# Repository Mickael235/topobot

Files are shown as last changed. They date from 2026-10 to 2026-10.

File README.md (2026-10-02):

# TopoBot

<p align="center">
  <strong>Autonomous holonomic robot for automated topographic surface-flatness inspection</strong><br>
  ENSIM × ESGT · 4th-year Engineering Project · 2025–2026
</p>

<p align="center">
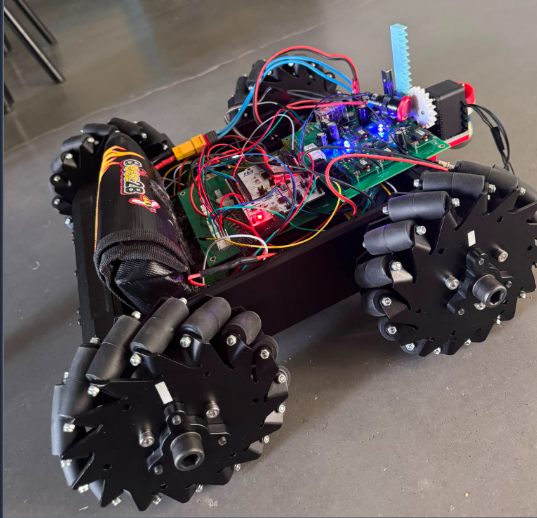
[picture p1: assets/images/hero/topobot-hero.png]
TopoBot holonomic mobile robot
  
</p>

<p align="center">
  <strong>STM32 F446RE · Raspberry Pi · Mecanum · Encoders · AX-12 · XBee · KiCad · Python · C</strong>
</p>

---

## Project overview

**TopoBot** is a holonomic mobile robot developed to automate the repetitive part of a topographic surface-flatness survey.

In a conventional workflow, an operator manually moves a reflector from point to point while another operator operates the total station. TopoBot was designed to replace this manual point-by-point displacement with a configurable robotic mission:

1. define the measurement grid;
2. navigate to each waypoint;
3. deploy the topographic prism;
4. trigger / acquire the measurement;
5. recover the coordinates;
6. store and export the results.

The project combines **robotics, embedded control, electronics, radio communication, software supervision and topographic instrumentation** in one integrated prototype.

> **Project status:** the main hardware/software building blocks were integrated and validated on the prototype. Final industrial-grade accuracy, complete odometry/total-station fusion and a full production flatness campaign remain future work.

---

## Project at a glance

| Item | Implementation |
|---|---|
| Mobile base | Lynxmotion A4WD3 with 4 Mecanum wheels |
| Real-time controller | STM32 Nucleo F446RE |
| High-level computer | Raspberry Pi 4 |
| Motor power stage | 2 × Sabertooth motor drivers |
| Motion feedback | 4 incremental wheel encoders |
| Prism mechanism | AX-12 servomotor + rack-and-pinion mechanism |
| Station communication | XBee S2C radio link + serial / RS232 interface |
| Supervision | TopoBot Manager on tablet / browser |
| Data storage | SQLite on Raspberry Pi |
| Export | CSV |
| Real-time control loop | 100 Hz |
| Project budget | €500 |
| Actual project cost | €318.26 |
| Team | 4 engineering students |

### Design target

The functional specification targeted a configurable survey grid up to **50 m × 50 m**, with a nominal **0.5 m grid spacing** and a **40 mm spherical reflector**.

This is a **design requirement**, not a claim that the complete 50 × 50 m campaign was validated during the project.

---

# 1. Problem and mission

Manual surface inspection with a total station is repetitive: the reflector must be moved and positioned at many points, while measurements are triggered and recorded.

TopoBot aims to transform this workflow into a supervised autonomous sequence.

<p align="center">
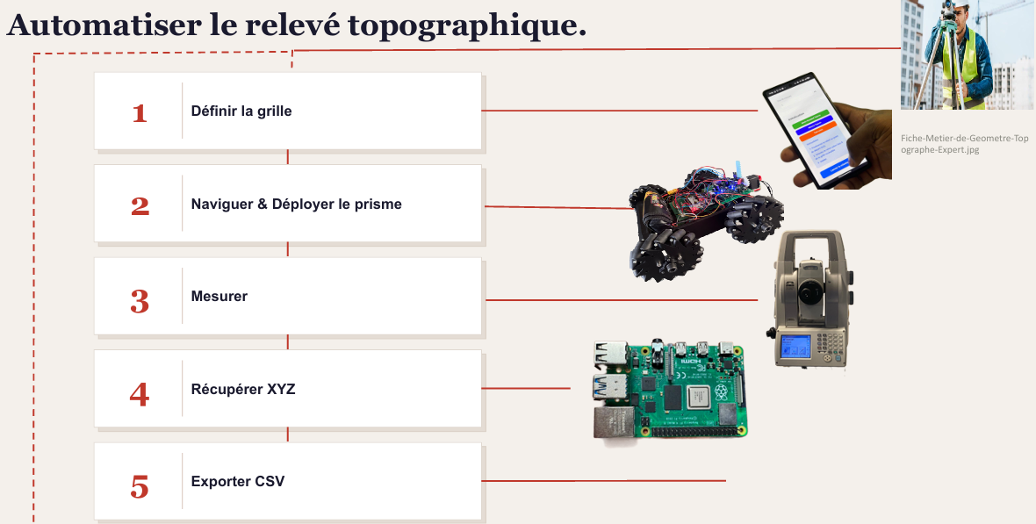
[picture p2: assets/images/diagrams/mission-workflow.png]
TopoBot automated topographic survey workflow
  
</p>

## Nominal survey cycle

```text
Define grid
    ?
Generate waypoints
    ?
Navigate to waypoint
    ?
Stabilize robot
    ?
Deploy prism
    ?
Trigger total-station measurement
    ?
Recover XYZ / angles / distance
    ?
Retract prism
    ?
Store point in SQLite
    ?
Send progress to TopoBot Manager
    ?
Next waypoint
    ?
Export mission data to CSV
```

The trajectory is generated as a **boustrophedon path**: the direction alternates from one grid row to the next to reduce unnecessary travel.

---

# 2. Functional architecture

The robot must interact with the surveyor, the surface, the total station, the energy source and the safety environment.

<p align="center">
  TopoBot functional architecture and main requirements
</p>

The main service functions are:

| Ref. | Function | Main requirement |
|---|---|---|
| FP1 | Move and orient the reflector | Configurable grid, 40 mm reflector |
| FC1 | Communicate with the total station | XBee S2C radio link, commands + coordinates |
| FC2 | Provide configuration and monitoring | Tablet / smartphone interface |
| FC3 | Provide energy autonomy | Rechargeable battery |
| FC4 | Operate in an indoor environment | Flat surface, future obstacle/drop detection |
| FC5 | Respect safety/environment constraints | Emergency stop and safe integration |

---

# 3. Robot structure

TopoBot is not a single-controller robot. It uses a **distributed architecture** in which the computational responsibilities are separated.

## Three control levels

```mermaid
flowchart LR
    UI["Tablet / Browser<br><b>TopoBot Manager</b>"]
    PI["Raspberry Pi 4<br><b>Mission supervisor / middleware</b>"]
    MCU["STM32 F446RE<br><b>Real-time motion controller</b>"]

    UI <-->|Network / Web interface| PI
    PI <-->|Binary serial protocol| MCU
```

### Level 1 — Tablet / front-end

The operator uses TopoBot Manager to:

- connect to the robot;
- configure the survey area;
- choose the grid spacing;
- initialize the measurement mode;
- launch the mission;
- monitor progress;
- read logs and telemetry;
- stop the robot;
- export results.

### Level 2 — Raspberry Pi / middleware

The Raspberry Pi acts as the high-level computer. It is responsible for:

- mission generation;
- waypoint sequencing;
- communication with the STM32;
- communication with the total station;
- measurement orchestration;
- SQLite data storage;
- WebSocket progress updates;
- CSV export;
- serving the supervision application.

### Level 3 — STM32 / real-time control

The STM32 F446RE performs the time-critical functions:

- encoder acquisition;
- odometry;
- motion state machine;
- closed-loop motor control;
- Sabertooth command generation;
- emergency-stop handling;
- AX-12 prism control;
- execution of high-level motion orders.

This separation keeps real-time control local to the microcontroller while the Raspberry Pi focuses on supervision and mission logic.

---

# 4. Complete hardware architecture

```mermaid
flowchart TD
    APP["TopoBot Manager<br>Tablet / PC"]
    RPI["Raspberry Pi 4<br>Mission supervisor"]
    STM["STM32 F446RE<br>100 Hz real-time control"]
    PCB["Custom control board<br>KiCad / JLCPCB"]

    ENC["4 wheel encoders"]
    SAB["2 × Sabertooth<br>motor drivers"]
    MOT["4 DC motors<br>4 Mecanum wheels"]
    AX["AX-12 servo<br>Prism deployment"]
    ESTOP["Emergency stop"]
    BATT["Battery monitoring"]

    XB1["XBee S2C #1"]
    XB2["XBee S2C #2"]
    RS232["MAX3232 / RS232"]
    TOPCON["Robotic total station"]

    APP <-->|Supervision| RPI
    RPI <-->|Binary serial protocol| STM

    ENC --> STM
    STM --> PCB
    PCB --> SAB
    SAB --> MOT
    STM --> AX
    ESTOP --> PCB
    BATT --> PCB

    RPI <-->|USB / UART serial| XB1
    XB1 <-. "Radio" .-> XB2
    XB2 <-->|Serial| RS232
    RS232 <-->|RS232| TOPCON
```

<p align="center">
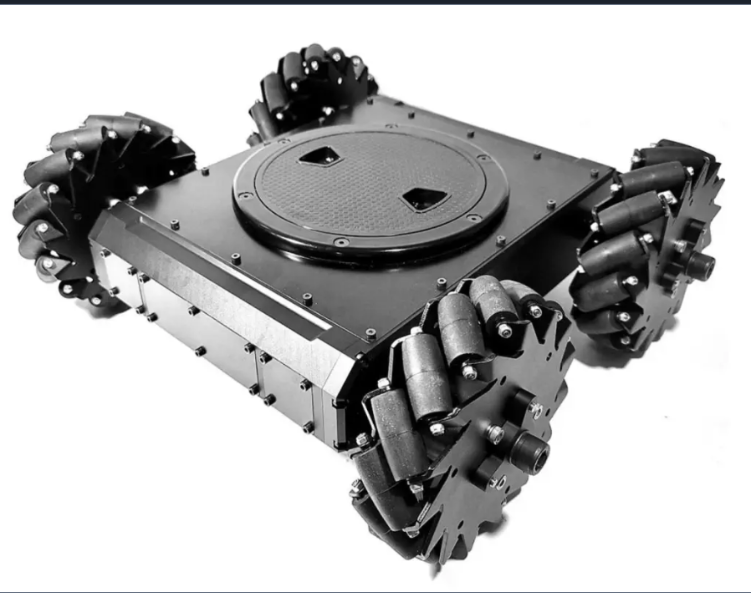
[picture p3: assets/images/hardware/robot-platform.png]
TopoBot physical robot
  
</p>

---

# 5. Holonomic Mecanum platform

The Lynxmotion A4WD3 base uses four Mecanum wheels, allowing longitudinal, lateral and rotational motion.

## Wheel-direction combinations

| Motion | Front Left | Front Right | Rear Left | Rear Right |
|---|---:|---:|---:|---:|
| Forward | + | + | + | + |
| Backward | - | - | - | - |
| Left translation | - | + | + | - |
| Right translation | + | - | - | + |
| Left rotation | - | + | - | + |
| Right rotation | + | - | + | - |

The current survey mission mainly uses **translations with a constant orientation**. Nevertheless, the command interface preserves the full pose parameter:

```text
MOVE_TO(x, y, theta)
```

This keeps the architecture extensible toward complete pose control.

## Physical testing

Early tests demonstrated the expected Mecanum motion but also revealed parasitic rotation during straight translations due to wheel/motor asymmetry.

This led to:

- individual wheel testing;
- lower-speed validation;
- exploitation of encoder feedback;
- progressive closed-loop tuning.

---

# 6. STM32 real-time control

The embedded firmware is organised around several modules:

```text
STM32 firmware
+-- Mecanum kinematics
+-- Encoder acquisition
+-- Odometry
+-- PID / motion control
+-- Robot state machine
+-- Raspberry Pi protocol
+-- AX-12 prism control
+-- Safety / robot configuration
```

The repository contains the STM32 project in:

```text
firmware/stm32/
```

## Robot state machine

The controller uses the following main states:

```mermaid
stateDiagram-v2
    [*] --> IDLE
    IDLE --> MOVING: MOVE_TO
    MOVING --> SETTLING: target reached
    SETTLING --> DONE: position confirmed
    DONE --> IDLE
    MOVING --> ERROR: fault
    SETTLING --> ERROR: fault
    IDLE --> ESTOP: emergency stop
    MOVING --> ESTOP: emergency stop
    SETTLING --> ESTOP: emergency stop
```

Main states:

- `IDLE` — waiting for a command;
- `MOVING` — moving toward the target;
- `SETTLING` — stabilizing around the waypoint;
- `DONE` — waypoint reached and confirmed;
- `ERROR` / `ESTOP` — error or emergency stop.

The Raspberry Pi only sends the next waypoint after receiving a `DONE` status.

---

# 7. Raspberry Pi ? STM32 protocol

The Raspberry Pi does not directly control the motors.

It sends high-level commands to the STM32 using a lightweight binary protocol:

```text
[ START | CMD | LEN | PAYLOAD | CRC ]
```

The project uses a simple XOR-based CRC over the command, payload length and payload.

## Main commands

| Command | Role |
|---|---|
| `MOVE_TO` | Reach target pose `(x, y, ?)` |
| `STOP` | Immediate robot stop |
| `RESET_ODOM` | Reset odometry before a mission |
| `GET_STATUS` | Read position, speed and current state |
| `DEPLOY_PRISM` | Deploy the topographic prism |
| `RETRACT_PRISM` | Retract the prism |

The STM32 returns status frames such as:

```text
STATUS
DONE
ERROR
```

These messages allow the Raspberry Pi backend to orchestrate the mission without interfering with the real-time control loop.

---

# 8. Automatic mission logic

The mission is generated from:

```text
Zone width  = X
Zone length = Y
Grid step   = p
```

The backend generates the waypoint set:

```text
(xi, yj)
xi = i × p
yj = j × p
```

and orders them in a boustrophedon trajectory.

## Exact mission order

```text
1. RESET_ODOM
   +- Reset the robot local reference before starting.

2. Generate waypoints
   +- Build the complete boustrophedon measurement grid.

3. For each waypoint:
   +- Send MOVE_TO(x, y, ?)
   +- Wait for STM32 STATUS updates
   +- Continue only after DONE

4. If measurement mode is enabled:
   +- DEPLOY_PRISM
   +- Trigger / request Topcon measurement
   +- Recover measurement values
   +- RETRACT_PRISM

5. Save measurement
   +- Timestamp + local coordinates + station data ? SQLite

6. Notify front-end
   +- Mission progress and current data ? WebSocket

7. Continue with next waypoint

8. End mission
   +- Export the recorded dataset to CSV
```

<p align="center">
  TopoBot mission order
</p>

A **station-independent test mode** was also kept. In this mode the robot can execute the grid with simulated measurement values, making it possible to debug navigation without depending on the topographic instrument.

---

# 9. Prism deployment mechanism

The topographic reflector is mounted on a rack-and-pinion mechanism actuated by an **AX-12 servomotor**.

The mechanism is responsible for:

```text
RETRACTED
    ?
DEPLOY_PRISM
    ?
Prism positioned for measurement
    ?
Total-station acquisition
    ?
RETRACT_PRISM
    ?
Robot resumes navigation
```

This sequence is synchronized with waypoint validation so that measurements are not requested while the robot is still moving.

---

# 10. Custom electronics

A custom control board was designed in **KiCad**, manufactured by **JLCPCB**, assembled and integrated into the robot.

<p align="center">
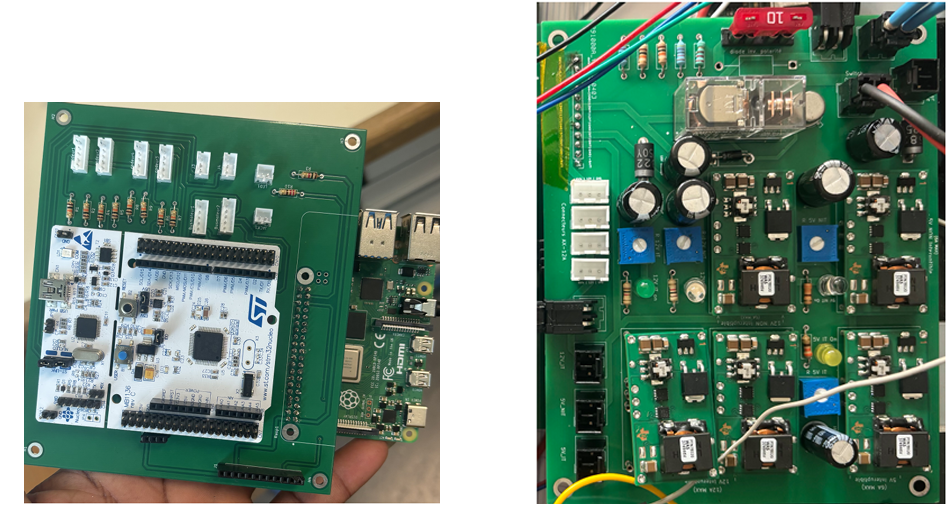
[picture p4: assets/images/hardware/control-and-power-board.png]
TopoBot custom control and power electronics
  
</p>

The control electronics centralize:

- four encoder interfaces;
- STM32 connectivity;
- Sabertooth motor-control connections;
- AX-12 interface;
- emergency-stop circuitry;
- centralized power management;
- analog battery monitoring;
- expansion ports for future ultrasonic sensors.

The pre-existing power board was reused, while the **control board was redesigned specifically for this project**.

The KiCad project and Gerber manufacturing files are available under:

```text
hardware/control-board/
+-- kicad/
+-- manufacturing/
    +-- gerbers/
```

---

# 11. XBee radio link and total-station interface

TopoBot communicates with the robotic total station through a dedicated radio/serial chain.

<p align="center">
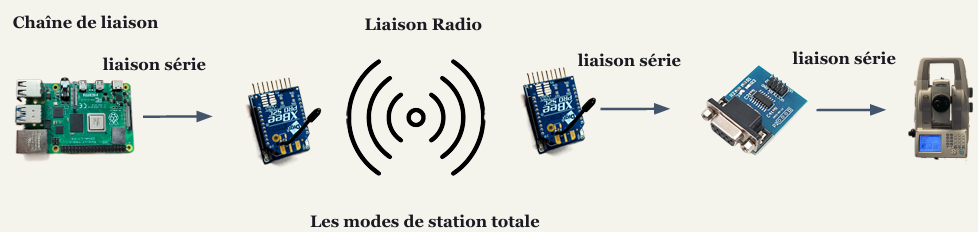
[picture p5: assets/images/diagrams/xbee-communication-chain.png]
XBee communication chain between Raspberry Pi and total station
  
</p>

## Communication chain

```text
Raspberry Pi
    ¦
    ¦ USB / UART serial
    ?
XBee S2C #1
    ))) RADIO (((
XBee S2C #2
    ¦
    ¦ Serial
    ?
MAX3232 / RS232 converter
    ¦
    ¦ RS232
    ?
Robotic total station
```

## XBee configuration used during the project

| Parameter | Configuration |
|---|---|
| Baud rate | 9600 |
| Data bits | 8 |
| Parity | None |
| Stop bits | 1 |
| Flow control | None |
| Channel | `C` / `0x0C` |
| PAN ID | `B332` |

The modules were configured using **Digi XCTU**.

## Total-station operating modes

The project explored three main station modes:

### Standard (`std`)
High-precision fixed measurement using fine targeting.

### Tracking (`trk`)
Fast tracking / targeting of a moving reflector.

### Continuous tracking
Continuous acquisition of distances and horizontal/vertical angles.

The automated acquisition sequence uses the station together with the robot prism workflow to recover the current measured point and feed it back into the mission data.

> **Known limitation:** the XBee radio link showed intermittent reliability problems during field testing. Improving the radio layer is one of the main future-work items.

---

# 12. TopoBot Manager

**TopoBot Manager** is the supervision interface designed for tablet use.

Its purpose is to hide the complexity of the robot, STM32, Raspberry Pi and total station behind a guided workflow.

<p align="center">
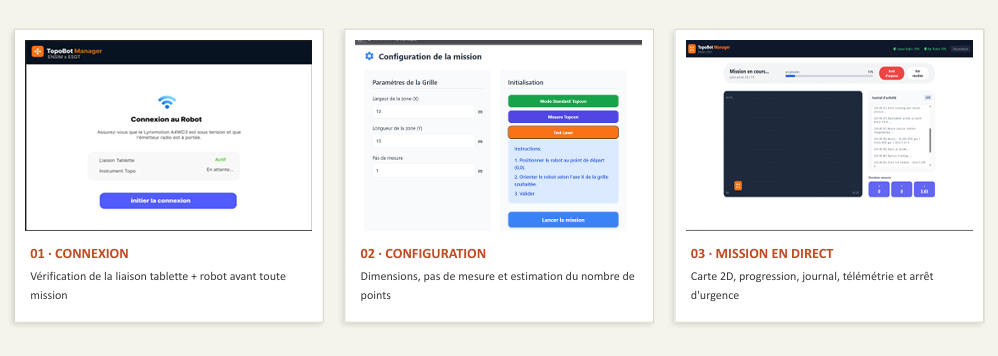
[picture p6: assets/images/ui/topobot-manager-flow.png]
TopoBot Manager connection, configuration and live mission screens
  
</p>

The application follows three main user stages.

## 01 — Connection

Before a mission starts, the interface verifies that the robot and measurement system are reachable.

Typical checks include:

- robot / Raspberry Pi connectivity;
- total-station link state;
- initialization readiness.

The operator cannot proceed until the system is ready.

## 02 — Mission configuration

The operator defines:

- survey width `X`;
- survey length `Y`;
- measurement step `p`;
- measurement mode.

The backend uses these values to determine the grid and generate the mission waypoints.

<p align="center">
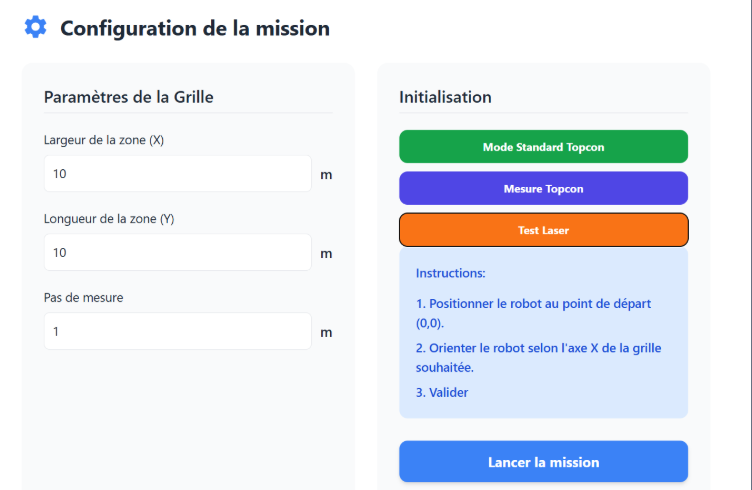
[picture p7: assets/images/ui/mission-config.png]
TopoBot Manager mission configuration
  
</p>

## 03 — Live mission supervision

During execution, the interface displays:

- mission progress;
- current point;
- 2D map of the grid;
- robot position;
- completed measurement points;
- activity/event log;
- latest measurement values;
- radio / system information;
- emergency-stop action.

<p align="center">
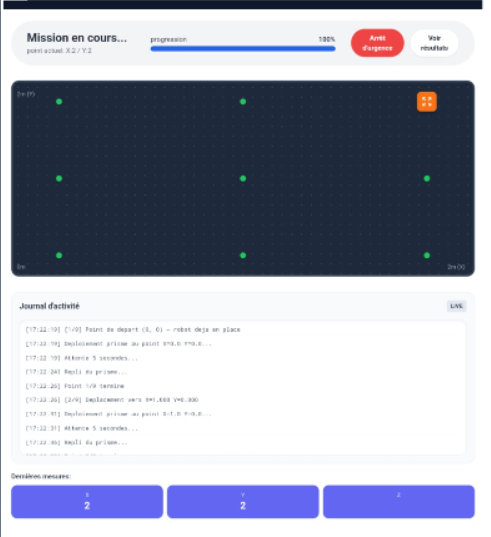
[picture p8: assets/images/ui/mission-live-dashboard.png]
TopoBot Manager live mission dashboard
  
</p>

---

# 13. Software communication layers

The complete information flow can be summarized as:

```text
+--------------------------------------+
¦ Tablet / Browser                    ¦
¦ TopoBot Manager                     ¦
¦ - configuration                     ¦
¦ - live map                          ¦
¦ - progress                          ¦
¦ - logs                              ¦
¦ - emergency stop                    ¦
+--------------------------------------+
                    ¦ HTTP / WebSocket
                    ?
+--------------------------------------+
¦ Raspberry Pi                        ¦
¦ Middleware / Mission Supervisor     ¦
¦ - route generation                  ¦
¦ - waypoint orchestration            ¦
¦ - SQLite                            ¦
¦ - CSV export                        ¦
¦ - total-station communication       ¦
+--------------------------------------+
                ¦               ¦
        Binary serial           ¦ XBee / serial
                ¦               ¦
                ?               ?
+----------------------+   +---------------------+
¦ STM32 F446RE         ¦   ¦ Robotic total      ¦
¦ - odometry           ¦   ¦ station            ¦
¦ - encoders           ¦   ¦ - measurement      ¦
¦ - PID                ¦   ¦ - tracking         ¦
¦ - motors             ¦   ¦ - XYZ / angles     ¦
¦ - AX-12              ¦   +---------------------+
+----------------------+
```

---

# 14. Data acquisition and export

Each measurement point is stored locally on the Raspberry Pi.

The project uses **SQLite** for mission data and exposes the final dataset through **CSV export**.

## Recorded fields

| Field | Meaning |
|---|---|
| `ID` | Unique measurement-point identifier |
| `HEURE` | Acquisition timestamp |
| `X`, `Y` | Local planar coordinates |
| `HZ` | Horizontal station angle |
| `V` | Vertical station angle |
| `DIST` | Radial distance measured by the station |

The mission data lifecycle is:

```text
Connection
    ?
Geometry configuration
    ?
Survey supervision
    ?
SQLite storage
    ?
CSV export
```

The CSV format was chosen to keep the results directly usable in spreadsheets and topographic post-processing tools.

---

# 15. Validation

The project was developed using progressive integration and physical tests.

## Tests performed

- individual motor-direction tests;
- Mecanum wheel-combination tests;
- forward/backward translation;
- lateral translation;
- encoder acquisition;
- odometry;
- Raspberry Pi ? STM32 communication;
- high-level `MOVE_TO` commands;
- robot state-machine behavior;
- AX-12 prism deployment/retraction;
- XBee radio communication;
- total-station operating modes;
- TopoBot Manager connection/configuration/live monitoring;
- mission generation and waypoint sequencing;
- station-independent simulated-measurement mode.

## Current validation status

| Subsystem | Status |
|---|---|
| Mecanum basic motion | ? Validated |
| STM32 real-time architecture | ? Implemented |
| Encoder feedback / odometry | ? Integrated |
| Raspberry Pi ? STM32 protocol | ? Implemented |
| High-level waypoint mission logic | ? Implemented |
| AX-12 prism deployment | ? Integrated and validated |
| Custom control PCB | ? Designed, manufactured and assembled |
| TopoBot Manager | ? Functional |
| Total-station communication modes | ? Exercised |
| XBee field robustness | ?? Functional but unreliable in some tests |
| Closed-loop tuning | ?? Requires finer adjustment |
| Odometry + total-station fusion | ?? Future work |
| Complete production flatness campaign | ?? Still to be finalized |

The goal of this repository is to present the **real engineering state of the prototype**, including both validated subsystems and remaining technical limitations.

---

# 16. Engineering challenges encountered

## Wheel synchronization

The first physical tests revealed unwanted rotation during straight movement.

Probable causes included:

- different mechanical behavior between motors;
- left/right timing asymmetry;
- open-loop control limitations.

Encoder feedback and closed-loop control were introduced to improve trajectory stability.

## Odometry drift

Wheel odometry accumulates errors when the wheels slip or the ground is irregular.

A future version should fuse:

```text
Wheel odometry
      +
High-precision total-station coordinates
      ?
Corrected robot localization
```

## Radio robustness

The XBee solution proved useful for prototyping but showed intermittent signal losses.

A more robust professional radio solution would be preferable for field deployment.

## Wiring reliability

The prototype contains a significant amount of point-to-point wiring. A future revision should use:

- locking connectors;
- improved cable routing;
- additional functions integrated directly onto the PCB.

## Active safety

Obstacle/drop sensors were planned in the architecture but were not fully operational in the final prototype.

---

# 17. My contribution

This was a **four-person team project** with distinct technical work packages.

My contribution focused primarily on **control, kinematics and motion validation**, including:

- development and validation of robot movement behavior;
- Mecanum motion testing;
- trajectory-execution testing;
- analysis of encoder feedback and positioning errors;
- participation in odometry / motion-control integration;
- contribution to waypoint and mission-motion logic;
- integration and testing of the AX-12 prism mechanism;
- physical prototype testing and debugging.

The complete project also includes major contributions from the other team members in supervision/UI, XBee communication and electronics/PCB integration.

---

# 18. Team organization

| Team member | Main work package |
|---|---|
| Bénéwindé Kontiebo | Project management · Supervision · HMI |
| Aymane Fariss | Communication · XBee / total-station link |
| Arsène Nguenang Youkap | Electronics · PCB · hardware integration |
| **Michael Essomba** | **Control · kinematics · AX-12 prism mechanism** |

The project was managed using an agile-inspired workflow with regular synchronization and milestone reviews.

---

# 19. Budget and reuse strategy

The project operated under a **€500 budget**.

| Metric | Value |
|---|---:|
| Available budget | €500 |
| Actual project cost | **€318.26** |
| Remaining budget | €181.74 |
| Budget utilization | ~64% |

A significant part of the platform was reused from previous cohorts:

- Lynxmotion chassis;
- DC motors;
- Mecanum wheels;
- Sabertooth drivers;
- XBee modules;
- AX-12 servo;
- prism mechanism;
- existing power board.

New spending focused mainly on the Raspberry Pi, STM32 boards, control electronics, passive components and PCB manufacturing.

---

# 20. Repository structure

```text
topobot/
+-- README.md
+-- .gitignore
¦
+-- assets/
¦   +-- images/
¦   ¦   +-- hero/
¦   ¦   ¦   +-- topobot-hero.png
¦   ¦   ¦
¦   ¦   +-- diagrams/
¦   ¦   ¦   +-- functional-architecture.png
¦   ¦   ¦   +-- mission-workflow.png
¦   ¦   ¦   +-- xbee-communication-chain.png
¦   ¦   ¦
¦   ¦   +-- hardware/
¦   ¦   ¦   +-- robot-platform.png
¦   ¦   ¦   +-- control-and-power-board.png
¦   ¦   ¦   +-- total-station.png
¦   ¦   ¦   +-- robot-cad-render.png
¦   ¦   ¦
¦   ¦   +-- ui/
¦   ¦       +-- topobot-manager-flow.png
¦   ¦       +-- mission-config.png
¦   ¦       +-- mission-live-dashboard.png
¦   ¦
¦   +-- video/
¦       +-- topobot-demo.mp4
¦
+-- docs/
¦   +-- presentation/
¦   +-- report/
¦   +-- technical/
¦
+-- firmware/
¦   +-- stm32/
¦
+-- hardware/
¦   +-- control-board/
¦       +-- kicad/
¦       +-- manufacturing/
¦           +-- gerbers/
¦
+-- software/
    +-- raspberry-pi/
    ¦   +-- tests/
    ¦
    +-- topobot-manager/
        +-- backend/
        +-- frontend/
```

Generated build files, local databases, virtual environments, IDE temporary files and dependency directories are intentionally excluded from version control.

---

# 21. Technologies

### Embedded systems

`C` · `STM32 F446RE` · `STM32CubeIDE` · `HAL`

### Robotics and control

`Mecanum kinematics` · `Encoders` · `Odometry` · `PID` · `State machine` · `AX-12`

### High-level software

`Python` · `Raspberry Pi` · `SQLite` · `WebSocket`

### Communication

`UART` · `Serial` · `XBee S2C` · `RS232`

### Electronics

`KiCad` · `PCB design` · `Gerber` · `JLCPCB`

### Instrumentation

`Robotic total station` · `Topographic prism` · `Tracking`

### Development

`Git` · `GitHub` · `Hardware testing` · `Technical documentation`

---

# 22. Demo

A short demonstration of the physical prototype is available here:

### [? Watch the TopoBot demo](assets/video/topobot-demo.mp4)

---

# 23. Documentation

Detailed engineering documentation is available in [`docs/`](docs/).

Main documents:

- [Final project report](docs/report/Rapport_final.pdf)
- [Project presentation](docs/presentation/TopoBot_Presentation.pdf)
- [STM32 firmware documentation](docs/technical/firmware/)
- [Hardware and wiring documentation](docs/technical/hardware/)
- [Raspberry Pi documentation](docs/technical/raspberry-pi/)
- [Testing documentation](docs/technical/tests/)
- [Odometry, PID and validation documentation](docs/technical/advanced/)

---

# 24. Future work

The next engineering priorities are:

1. **PID tuning**  
   Reduce oscillations and trajectory error.

2. **Odometry calibration**  
   Improve the estimation of `x`, `y` and `?`.

3. **Odometry / total-station sensor fusion**  
   Correct wheel-slip drift using high-precision station feedback.

4. **Radio reliability**  
   Replace or harden the XBee communication chain for field use.

5. **Active navigation safety**  
   Integrate obstacle, drop and stair detection.

6. **Wiring redesign**  
   Reduce point-to-point wiring and use locking connectors.

7. **Large-grid validation**  
   Validate longer missions and repeated surveys under realistic conditions.

8. **Full flatness campaign**  
   Complete the end-to-end autonomous survey and compare results against a reference workflow.

---

# 25. Project outcome

TopoBot evolved from an inherited mechanical platform into an integrated robotic prototype combining:

- a redesigned embedded architecture;
- STM32 real-time motion control;
- Raspberry Pi mission supervision;
- custom control electronics;
- Mecanum mobility;
- encoder odometry;
- AX-12 prism deployment;
- XBee / total-station communication;
- tablet-based mission supervision;
- local measurement storage and CSV export.

The project demonstrates the feasibility of automating a topographic surface-inspection workflow while also identifying the engineering work still required to reach robust field deployment.

---

# Project team

**ENSIM × ESGT — Le Mans University**  
Academic year: **2025–2026**

- Bénéwindé Kontiebo
- **Michael Essomba**
- Arsène Nguenang Youkap
- Aymane Fariss

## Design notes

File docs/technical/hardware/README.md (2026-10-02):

# 2 — Matériel

Ce chapitre décrit les composants du robot et comment ils sont reliés.
Voir aussi :
- [Brochage STM32](Brochage_STM32.md) — tableau complet des broches
- [Câblage](Cablage.md) — détail des bus et des liaisons

## 2.1 Liste des composants principaux

| Composant | Rôle | Interface vers le STM32 |
|---|---|---|
| **Carte STM32 Nucleo F446RE** | Calculateur temps réel | — |
| **Raspberry Pi** | Superviseur (serveur, station, web) | USB → USART2 (via ST‑Link) |
| **2× contrôleurs Sabertooth** | Pilotage des 4 moteurs DC | UART4 (PC10), bus partagé |
| **4× moteurs DC + réducteur** | Entraînement des roues mecanum | via Sabertooth |
| **4× encodeurs en quadrature** | Odométrie | TIM2, TIM3, TIM4, TIM8 |
| **Servo AX12 Dynamixel** | Déploiement du prisme | UART5 (PC12) |
| **Bouton d'arrêt d'urgence (ARU)** | Sécurité | GPIO PB14 |
| **Relais d'alimentation puissance** | Coupe l'alim moteurs | GPIO PA5 (Power_enable) |
| **Module XBee** | Liaison vers la station Topcon | USB sur la Raspberry Pi (FTDI) |
| **Station Topcon MS1AX** | Mesures topographiques | via XBee |
| **Prisme topographique** | Réflecteur visé par la station | monté sur le servo AX12 |
| **Capteur niveau batterie** | Mesure tension (ADC) | PA4 (ADC1_IN4) |

## 2.2 Schéma des liaisons

```
                         ┌───────────────────────────┐
                         │      STM32 F446RE          │
                         │                            │
  Raspberry Pi ──USB────►│ USART2 (PA2/PA3) 115200    │
  (ST-Link série)        │                            │
                         │ UART4  (PC10)  ────────────┼──► Sabertooth #1 (addr 128) ─► moteurs FL, RL
                         │   bus série partagé 9600   ┼──► Sabertooth #2 (addr 129) ─► moteurs FR, RR
                         │                            │
                         │ UART5  (PC12)  1 Mbps ─────┼──► Servo AX12 (prisme)
                         │                            │
                         │ TIM2 (PA0/PA1) ◄───────────┼─── Encodeur FR  🔴 hors service
                         │ TIM3 (PA6/PA7) ◄───────────┼─── Encodeur RR  🟢
                         │ TIM4 (PB6/PB7) ◄───────────┼─── Encodeur FL  🔴 hors service
                         │ TIM8 (PC6/PC7) ◄───────────┼─── Encodeur RL  🟢
                         │                            │
                         │ PB14 ◄─────────────────────┼─── Bouton ARU
                         │ PA5  ────────────────────► relais alim puissance
                         │ PA4  ◄── tension batterie  │
                         └────────────────────────────┘

  Raspberry Pi ──USB(FTDI)──► XBee ))) ((( XBee ──► Station Topcon MS1AX
```

## 2.3 Alimentation

- Une **batterie** alimente la partie puissance (moteurs via Sabertooth).
- Le STM32 active la puissance via le **relais sur PA5** (`Power_enable_stm`).
  Au démarrage le firmware met PA5 à l'état haut (cf. `main.c`, juste après
  l'init) pour autoriser le courant vers les Sabertooth.
- La **tension batterie** est lisible sur l'ADC (PA4 / `Battery_level`). Cette
  mesure n'est pas encore exploitée dans le logiciel — piste d'amélioration
  (cf. [passation](../08_Passation/README.md)).

> ⚠️ Couper la puissance (relais / batterie) avant toute intervention sur le
> câblage. Le bouton ARU coupe la **commande** mais vérifiez toujours
> physiquement.

## 2.4 État du matériel (fin d'année)

| Élément | État | Remarque |
|---|---|---|
| Moteurs + Sabertooth | 🟢 | Les 4 roues répondent (voir polarités dans `mecanum.c`) |
| **Les 4 encodeurs** (TIM2/3/4/8) | 🟡 | **Fonctionnent**, mais comptage intermittent à cause de la carte de commande (voir ci‑dessous) |
| Carte de commande (interface encodeurs) | 🟡 | **Problèmes intermittents** : certains tics ne remontent pas tant que la carte/les connecteurs ne sont pas bien en place |
| Servo AX12 | 🟢 | Déploie / replie le prisme |
| Bouton ARU | 🟢 | Avec filtrage anti‑parasites moteurs (debounce) |
| Station Topcon + XBee | 🟡 | Fonctionne mais sensible à la config série / au timing |
| Mesure batterie | 🔴 | Câblée mais non exploitée par le logiciel |

> ⚠️ **Les 4 encodeurs sont fonctionnels.** Le problème vient de la **carte de
> commande** : selon son état (connecteurs, contacts), certains encodeurs
> peuvent **ne pas compter** ponctuellement, ce qui **fausse l'odométrie**.
>
> **PROCÉDURE OBLIGATOIRE avant chaque test** : lancer `test_encoders.py`,
> **tourner chaque roue à la main** une par une, et vérifier que les tics de
> chacune des 4 roues augmentent bien. Si une roue ne compte pas → vérifier /
> repositionner la carte de commande **avant** de continuer, sinon tous les
> déplacements asservis seront faux.
>
> Note : le code firmware actuel (`robot_config.h`, mode `ODOM_REAR_ONLY=1` et
> commentaires « HORS SERVICE ») reflète un **ancien diagnostic** où seuls les
> encodeurs arrière étaient lus. Comme les 4 fonctionnent, ce mode peut être
> repassé à `0` **une fois le comptage des 4 roues confirmé** (voir
> [firmware](../03_Firmware_STM32/Modules.md) et
> [passation](../08_Passation/README.md)).

## 2.5 Cartes électroniques (KiCad)

Les cartes d'interface/alimentation conçues cette année seront documentées dans
le dossier [`07_KiCad/`](../07_KiCad/README.md) : déposez‑y les fichiers
sources KiCad (schémas, routage, BOM, gerbers).

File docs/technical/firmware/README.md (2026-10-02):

# 3 — Firmware STM32

Le firmware est le programme temps réel embarqué dans le STM32 F446RE. Il vit
dans le dossier `Core/` (le dossier `Drivers/` est la bibliothèque HAL générée,
à ne pas modifier).

Voir aussi :
- [Protocole de communication](Protocole_Communication.md) — trames Pi ↔ STM32
- [Modules firmware](Modules.md) — description fichier par fichier

## 3.1 Environnement et compilation

- **IDE** : STM32CubeIDE (basé sur Eclipse + GCC ARM).
- **Ouvrir le projet** : *File ▸ Open Projects from File System…* → dossier
  `ProjetRobot`. Le `.cproject` / `.project` sont déjà présents.
- **Configuration matérielle** : `ProjetRobot.ioc` (CubeMX). Double‑cliquez
  pour modifier le brochage / les périphériques ; CubeMX régénère ensuite les
  fonctions `MX_*_Init` dans `main.c`.
- **Compiler** : marteau 🔨 (*Build*). Le binaire `.elf` est produit dans
  `Debug/`.
- **Flasher / déboguer** : insecte vert 🐞 (*Debug*) ou *Run*. La carte Nucleo
  embarque un ST‑Link, le flash se fait par USB sans matériel supplémentaire.

> **Règle d'or CubeMX** : tout code que vous écrivez doit rester entre les
> balises `/* USER CODE BEGIN ... */` et `/* USER CODE END ... */`. Tout ce qui
> est en dehors est **écrasé** à chaque régénération depuis le `.ioc`.

## 3.2 Architecture logicielle

Le firmware est organisé en couches, du bas niveau au haut niveau :

```
        ┌─────────────────────────────────────────────┐
        │              main.c (boucle while)           │
        │  - init des périphériques                    │
        │  - TIM6 100 Hz → flag velocity_tick          │
        │  - appelle Protocol_Process + RobotControl   │
        └───────────────┬───────────────┬──────────────┘
                        │               │
        ┌───────────────▼──┐   ┌────────▼───────────────┐
        │  protocol.c       │   │  robot_control.c       │
        │  (dialogue Pi)    │   │  (machine d'états +    │
        │                   │   │   asservissement x,y)  │
        └───────────────────┘   └──┬─────────┬───────┬───┘
                                   │         │       │
                       ┌───────────▼─┐ ┌─────▼────┐ ┌▼────────┐
                       │ odometry.c   │ │ pid.c    │ │ mecanum.c│
                       │ (pose x,y,θ) │ │ (régul.) │ │ (roues + │
                       │              │ │          │ │ Sabertooth)│
                       └──────────────┘ └──────────┘ └──────────┘

                       ax12.c  ←  pilotage servo prisme (appelé par protocol.c)
```

## 3.3 La boucle de contrôle 100 Hz

C'est le cœur temps réel. Mécanisme :

1. **TIM6** est configuré à **100 Hz** (`main.c`, `MX_TIM6_Init`). À chaque
   débordement, son interruption met le flag `velocity_tick = 1` (et **rien
   d'autre** : aucun travail bloquant en interruption).
2. La boucle `while(1)` de `main.c` :
   - traite les trames reçues de la Pi (`Protocol_Process()`),
   - et quand `velocity_tick` est levé, appelle `RobotControl_Update()`.
3. `RobotControl_Update()` (à 100 Hz) :
   - met à jour l'**odométrie** (lecture des encodeurs),
   - filtre l'**ARU**,
   - selon l'état, calcule les vitesses (asservissement) et les envoie aux
     **Sabertooth** via `Mecanum_SetVelocity()`.

> **Pourquoi l'envoi Sabertooth se fait en boucle principale et pas en
> interruption ?** L'envoi de 4 paquets à 9600 bauds prend ≈ 17 ms. Si on le
> faisait dans l'interruption TIM6 (priorité haute), il masquerait la réception
> USART2 pendant 17 ms → risque d'**overrun** (octets perdus, réception bloquée).
> En le faisant dans la boucle principale, la réception peut préempter
> normalement. **Ce point reste fragile** — voir
> [passation](../08_Passation/README.md).

## 3.4 La machine d'états du robot

Définie dans `robot_control.h` (`RobotState_t`) :

| État | Signification |
|---|---|
| `ROBOT_IDLE` | En attente. Peut recevoir des vitesses manuelles (`CMD_SET_VELOCITY`). |
| `ROBOT_MOVING` | Déplacement asservi en cours vers une cible (x, y). |
| `ROBOT_SETTLING` | (réservé) stabilisation sur la cible. |
| `ROBOT_DONE` | Cible atteinte et stabilisée. |
| `ROBOT_ESTOP` | Arrêt d'urgence (bouton ARU). |
| `ROBOT_ERROR` | Erreur (hors limites de grille, etc.). |

Transitions principales :
- `CMD_MOVE_TO` → `MOVING` ; convergence (pose stable `SETTLE_CYCLES` cycles) → `DONE`.
- ARU appuyé → `ESTOP` (depuis n'importe quel état).
- `CMD_STOP` / `CMD_RESET_ODOM` → retour à `IDLE`.

## 3.5 Stratégie d'asservissement (important)

L'asservissement de position est un **proportionnel pur saturé avec zone
morte**, pas un vrai PID. Choix volontaire, documenté dans `robot_control.c` :

```
vx = saturation(KP · erreur_x , ±VELOCITY_CAP) ; si |vx| < zone_morte → 0
vy = saturation(KP · erreur_y , ±VELOCITY_CAP) ; si |vy| < zone_morte → 0
```

Raisons :
1. **Pas d'intégrale (I)** → pas de windup, pas de dérive à l'arrêt.
2. **Pas de dérivée (D)** → pas de pic au démarrage qui saturait la commande.
3. Garder la sortie dans la plage `[zone_morte, VELOCITY_CAP]` où **toutes les
   roues répondent uniformément** (régime validé empiriquement vers 0,10 m/s).

S'y ajoutent :
- une **rampe d'accélération** (slew rate) pour démarrer en douceur,
- une **correction séquentielle des axes** : quand vx et vy sont proches en
  magnitude, on ne garde que l'axe dominant (sinon la cinématique mecanum met
  une paire de roues à ≈0 → déséquilibre).

Tous les paramètres (gains, plafonds, seuils, tolérances) sont centralisés dans
**`robot_config.h`** — c'est le fichier à éditer pour régler le comportement.

## 3.6 Fichier de configuration : `robot_config.h`

**À lire en entier.** Il regroupe :
- mapping et polarités des encodeurs,
- handles UART et adresses Sabertooth,
- paramètres AX12 (ID, positions, débit),
- dimensions du robot (rayon de roue, empattements),
- calibration de l'odométrie (`TICKS_PER_METER`),
- gains et limites de l'asservissement,
- fréquence de la boucle de contrôle.

> ⚠️ Plusieurs constantes portent la mention « à recalibrer » ou « à mesurer ».
> Voir [Calibration](../06_Calibration_Depannage.md).

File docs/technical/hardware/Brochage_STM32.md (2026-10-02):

# Brochage STM32 F446RE

Tableau complet des broches utilisées, extrait de la configuration CubeMX
(`ProjetRobot.ioc`). Les **étiquettes** (« Label ») sont celles définies dans
le `.ioc` et reprises dans le code.

> Pour modifier le brochage, ouvrez `ProjetRobot.ioc` dans STM32CubeIDE
> (double‑clic) plutôt que d'éditer le code à la main : CubeMX régénère
> ensuite les fonctions d'init dans `main.c`.

## Moteurs (signaux PWM + direction)

> Note : les moteurs sont en réalité pilotés par les **Sabertooth via UART4**
> (protocole série), pas directement par ces PWM. Ces broches PWM/DIR
> proviennent d'une première approche « pont en H direct » et restent câblées
> dans le `.ioc`. Le firmware actuel n'utilise PAS ces PWM pour la marche
> (voir `mecanum.c`).

| Broche | Label | Fonction | Périphérique |
|---|---|---|---|
| PA8  | Moteur_1_PWM | PWM moteur 1 | TIM1_CH1 |
| PA9  | Moteur_2_PWM | PWM moteur 2 | TIM1_CH2 |
| PA10 | Moteur_3_PWM | PWM moteur 3 | TIM1_CH3 |
| PA11 | Moteur_4_PWM | PWM moteur 4 | TIM1_CH4 |
| PB1  | Moteur_1_DIR | Direction moteur 1 | GPIO sortie |
| PB2  | Moteur_2_DIR | Direction moteur 2 | GPIO sortie |
| PB3  | Moteur_3_DIR | Direction moteur 3 | GPIO sortie |
| PB4  | Moteur_4_DIR | Direction moteur 4 | GPIO sortie |

## Encodeurs (mode quadrature)

| Broches | Labels | Roue | Timer | État |
|---|---|---|---|---|
| PA0 / PA1 | CodDA / CodDB | FR (avant droite) | TIM2 (CH1/CH2) | 🟡 OK, dépend de la carte de commande |
| PA6 / PA7 | CodDA2 / CodDB2 | RR (arrière droite) | TIM3 (CH1/CH2) | 🟡 OK, dépend de la carte de commande |
| PB6 / PB7 | CodGB / CodGA | FL (avant gauche) | TIM4 (CH1/CH2) | 🟡 OK, dépend de la carte de commande |
| PC6 / PC7 | CodG2B / CodGA2 | RL (arrière gauche) | TIM8 (CH1/CH2) | 🟡 OK, dépend de la carte de commande |

> **Les 4 encodeurs fonctionnent.** Mais selon l'état de la **carte de
> commande**, le comptage peut être intermittent → **vérifier les 4 roues avec
> `test_encoders.py` avant chaque test** (voir
> [Matériel §2.4](README.md#24-état-du-matériel-fin-dannée)).

> **Attention au mapping** : il a été vérifié expérimentalement par
> `test_motor_mapping.py` le 2026‑05‑22. Les encodeurs suffixés « 2 » sont à
> l'**arrière**. Côté gauche, les voies A/B sont permutées sur les canaux du
> timer → d'où les polarités `ENC_POL_*` négatives dans `robot_config.h`.

## Liaisons série (UART/USART)

| Broche | Label | Fonction | Périphérique | Débit |
|---|---|---|---|---|
| PA2 | data_AX12 *(nom historique)* | TX vers Raspberry Pi | USART2_TX | 115200 |
| PA3 | — | RX depuis Raspberry Pi | USART2_RX | 115200 |
| PC10 | Sabertooth1_TX | TX vers bus Sabertooth | UART4_TX | 9600 |
| PC11 | Sabertooth1_RX | RX bus Sabertooth (inutilisé) | UART4_RX | 9600 |
| PC12 | Sabertooth2_TX *(nom historique)* | TX vers servo AX12 | UART5_TX | 1 000 000 |
| PD2  | Sabertooth2_RX *(nom historique)* | RX AX12 | UART5_RX | 1 000 000 |

> ⚠️ **Pièges de nommage hérités.** Certains labels du `.ioc` ne correspondent
> plus à leur usage réel :
> - `data_AX12` (PA2) est en fait l'**USART2 vers la Raspberry Pi**, pas l'AX12.
> - `Sabertooth2_TX/RX` (PC12/PD2) sont en fait l'**UART5 vers le servo AX12**.
>
> Le code (`robot_config.h`) est la **source de vérité**, pas les labels du
> `.ioc`. Les deux Sabertooth partagent **un seul fil** sur PC10 (UART4) et
> sont distingués par leur adresse (128 / 129).

## GPIO divers

| Broche | Label | Fonction |
|---|---|---|
| PA5  | Power_enable_stm | Active le relais d'alimentation puissance (sortie) |
| PA4  | Battery_level | Mesure tension batterie (ADC1_IN4) |
| PB14 | ARU_signal | Entrée bouton arrêt d'urgence (pull‑up, actif à l'état bas) |

## Horloge et debug

| Broche | Fonction |
|---|---|
| PH0 / PH1 | Oscillateur (OSC_IN / OSC_OUT) |
| PA13 / PA14 | SWD debug (SWDIO / SWCLK) |

## Timers — récapitulatif des rôles

| Timer | Rôle |
|---|---|
| TIM1 | PWM moteurs (hérité, non utilisé pour la marche actuelle) |
| TIM2 | Encodeur FR 🟡 (dépend de la carte de commande) |
| TIM3 | Encodeur RR 🟡 (dépend de la carte de commande) |
| TIM4 | Encodeur FL 🟡 (dépend de la carte de commande) |
| TIM6 | **Base de temps 100 Hz** de la boucle de contrôle (configuré à la main dans `main.c`, PAS dans le `.ioc`) |
| TIM8 | Encodeur RL 🟡 (dépend de la carte de commande) |

> **À retenir** : TIM6 n'est **pas** généré par CubeMX. Il est initialisé
> manuellement dans `main.c` (`MX_TIM6_Init`). Si vous régénérez le projet
> depuis le `.ioc`, vérifiez que ce code n'a pas disparu, sinon la boucle de
> contrôle 100 Hz ne tourne plus.

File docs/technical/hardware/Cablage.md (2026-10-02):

# Câblage détaillé

Détail des bus et liaisons, avec les pièges rencontrés cette année.

## 1. Bus Sabertooth (moteurs) — UART4 / PC10

Les **deux Sabertooth partagent le même fil** de données série, branché sur
**PC10 (UART4_TX)** du STM32. C'est une liaison **unidirectionnelle** (le STM32
parle, les Sabertooth écoutent) en mode « **Packetized Serial** » à **9600
bauds**.

```
  STM32 PC10 (UART4_TX) ──┬──► S1 Sabertooth #1  (DIP réglés sur adresse 128) ─► moteurs FL + RL
                          └──► S1 Sabertooth #2  (DIP réglés sur adresse 129) ─► moteurs FR + RR
```

- La distinction entre les deux contrôleurs se fait par **l'adresse** envoyée
  en début de trame (128 ou 129), réglée sur les **micro‑switchs (DIP)** de
  chaque Sabertooth.
- Format d'une trame : `[Adresse] [Commande] [Valeur] [Checksum]`,
  `Checksum = (Adresse + Commande + Valeur) & 0x7F`. Voir `mecanum.c`.
- Sur chaque Sabertooth : moteur **A** = commandes 0/1 (avant/arrière),
  moteur **B** = commandes 4/5.

### Polarité de câblage des moteurs

Selon le sens de branchement physique des moteurs, certains tournent à
l'envers de la commande. C'est corrigé **logiciellement** dans `mecanum.c` :

```c
#define POL_FL  (-1)   // moteur câblé inversé
#define POL_FR  (+1)
#define POL_RL  (+1)
#define POL_RR  (-1)   // moteur câblé inversé
```

> Si vous rebranchez/remplacez un moteur et qu'il part dans le mauvais sens,
> changez le signe correspondant ici **plutôt que d'inverser les fils**.

## 2. Encodeurs — TIM2 / TIM3 / TIM4 / TIM8

Chaque encodeur a 2 voies (A et B) lues en **quadrature ×4** par un timer.
Voir le tableau dans [Brochage_STM32.md](Brochage_STM32.md).

Pièges :
- Côté **gauche**, les voies A/B sont **permutées** sur les canaux du timer →
  le compteur décompte quand la roue avance. Corrigé par `ENC_POL_*` négatif.
- **Les 4 encodeurs fonctionnent**, mais le comptage dépend de l'état de la
  **carte de commande** (interface des encodeurs) : si elle a un faux contact,
  une ou plusieurs roues cessent de compter et l'odométrie devient fausse.
  → **Vérifier les 4 roues avec `test_encoders.py` avant chaque test** (tourner
  chaque roue à la main, confirmer que les tics augmentent).

## 3. Servo AX12 (prisme) — UART5 / PC12

- Le servo **AX12 Dynamixel** est sur **UART5** (PC12 = TX, PD2 = RX), à
  **1 Mbps** (débit usine du servo). UART dédié → pas de conflit avec la Pi.
- Protocole **Dynamixel v1** : `FF FF [ID] [LEN] [INSTR] [PARAMS] [CHK]`.
  Voir `ax12.c`.
- L'**ID** du servo est `2` (`AX12_ID_PRISM` dans `robot_config.h`).
- Positions : `700` = déployé, `200` = rentré (échelle 0…1023 ↔ 0…300°).
  Ajustez ces valeurs si la course mécanique du prisme change.

> Le STM32 initialise UART5 à 115200 par CubeMX, puis `AX12_Init()` la
> **reconfigure à 1 Mbps**. Si vous changez le débit du servo, changez
> `AX12_BAUDRATE`.

## 4. Liaison Raspberry Pi ↔ STM32 — USART2 / PA2‑PA3

- **USART2** à **115200 bauds**, full‑duplex.
- Côté Pi, la connexion passe par l'**USB** (port série virtuel du ST‑Link de
  la Nucleo). Le chemin stable côté Pi ressemble à :
  `/dev/serial/by-id/usb-STMicroelectronics_STM32_STLink_...-if02`
  (défini dans `backend/main.py`, variable `STM32_PORT`).
- Protocole binaire maison : voir
  [Protocole de communication](../03_Firmware_STM32/Protocole_Communication.md).

## 5. Arrêt d'urgence (ARU) — PB14

- Entrée GPIO **PB14** avec **pull‑up** : actif à l'**état bas** (bouton
  appuyé → 0 V).
- Le firmware applique un **debounce** (5 lectures basses consécutives à
  100 Hz = 50 ms) pour ignorer les parasites électromagnétiques des moteurs.
  Voir `robot_control.c` (`aru_filter_step`).
- Quand l'ARU est actif : arrêt immédiat des moteurs, passage en état `ESTOP`,
  envoi de `ERR_ARU` à la Pi.

## 6. Liaison Raspberry Pi ↔ Station Topcon — XBee

- La station Topcon est reliée par **radio XBee**. Côté Pi, le XBee est branché
  en **USB via un adaptateur FTDI** → apparaît comme `/dev/ttyUSB0` (variable
  `TOPCON_PORT` dans `backend/main.py`).
- Débit : **9600 bauds**.
- Voir [Station Topcon](../04_Raspberry_Pi/Station_Topcon.md) pour les
  commandes.

> Vérifier le nom exact du port côté Pi avec `ls /dev/serial/by-id/` ou
> `dmesg | grep ttyUSB` — il peut changer selon l'ordre de branchement USB.

## 7. Relais d'alimentation puissance — PA5

- **PA5** (`Power_enable_stm`) commande un relais qui autorise le courant vers
  les Sabertooth.
- Mis à l'état **haut** par le firmware au démarrage (`main.c`). Tant que PA5
  est bas, les moteurs ne sont pas alimentés.

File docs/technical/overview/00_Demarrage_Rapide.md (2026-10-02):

# 00 — Démarrage rapide

Objectif : faire **bouger le robot** et **lancer une mission** le plus vite
possible. Les détails sont dans les chapitres suivants ; ici on va à
l'essentiel.

> ⚠️ **Sécurité d'abord.** La première fois, **surélevez le robot** (roues
> dans le vide) ou placez‑le dans une zone dégagée d'au moins 2 m. Gardez la
> main près du **bouton d'arrêt d'urgence (ARU)** et de l'alimentation
> puissance. Les moteurs peuvent démarrer brutalement.

> 🔴 **Réflexe à prendre dès le départ.** Avant **chaque** session de test,
> lancez `python test_encoders.py <PORT>` et **tournez les 4 roues à la main**
> pour vérifier que les tics sont bien comptés. Les 4 encodeurs marchent, mais
> la **carte de commande** est intermittente : une roue qui ne compte pas
> fausse toute l'odométrie. Voir [chapitre 5](05_Tests/README.md).

---

## 1. Ce qu'il vous faut

- Le robot assemblé, batterie chargée.
- Un **STM32 F446RE** flashé avec le firmware (voir étape 2).
- Une **Raspberry Pi** reliée au STM32 par USB (câble ST‑Link) et au XBee.
- Un PC ou une tablette sur le même réseau que la Pi.
- Logiciels : [STM32CubeIDE](https://www.st.com/en/development-tools/stm32cubeide.html)
  (firmware), Python 3.11+ et Node.js (application Pi).

---

## 2. Flasher le firmware STM32 (5 min)

1. Ouvrir **STM32CubeIDE** → *File ▸ Open Projects from File System…* → choisir
   le dossier `ProjetRobot`.
2. Brancher la carte en USB (ST‑Link intégré sur la Nucleo).
3. Cliquer sur le marteau 🔨 (*Build*), puis sur l'insecte vert 🐞 (*Debug*) ou
   *Run*. Le binaire est flashé automatiquement.

Détails et dépannage compilation : [chapitre 3](03_Firmware_STM32/README.md).

---

## 3. Tester les moteurs sans la Pi (optionnel mais recommandé)

Branchez votre PC directement sur le STM32 (port série virtuel ST‑Link) et
lancez, depuis le dossier `ProjetRobot` :

```bash
python test_comm.py COM6 --vx 0.08 --duration 2
```

(Remplacez `COM6` par votre port — sous Linux/Pi : `/dev/serial0` ou
`/dev/serial/by-id/usb-STMicroelectronics_STM32_STLink_...`.)

Le robot doit avancer, reculer, puis tourner. Si rien ne bouge → voir
[dépannage](06_Calibration_Depannage.md).

---

## 4. Lancer l'application TopoBot sur la Raspberry Pi (10 min)

### Backend (serveur)

```bash
cd topobot/topobot/backend
python3 -m venv venv            # si pas déjà fait
source venv/bin/activate
pip install -r requirements.txt
uvicorn main:app --host 0.0.0.0 --port 8000
```

Le serveur démarre. Vérifiez en bas du log qu'il a trouvé `frontend/dist`
(sinon : `cd ../frontend && npm install && npm run build`).

### Interface web

Depuis un navigateur sur le réseau : **`http://<IP_de_la_Pi>:8000`**

1. Écran de connexion → *Connecter*.
2. Écran de configuration → saisir largeur X, longueur Y et le pas de mesure.
3. *Démarrer la mission*. Le robot parcourt la grille, mesure à chaque point,
   et l'interface affiche la progression en temps réel.

Le gros **bouton rouge d'arrêt d'urgence** de l'interface coupe tout
immédiatement (mission + moteurs + tracking station).

Détails : [backend](04_Raspberry_Pi/README.md) ·
[interface](04_Raspberry_Pi/Interface_Web.md) ·
[station Topcon](04_Raspberry_Pi/Station_Topcon.md).

---

## 5. Vérifier que la station Topcon répond (avant une vraie mission)

```bash
python ms1ax.py /dev/ttyUSB0 mes      # lance une mesure simple
```

Si la station renvoie une trame CSV avec des nombres → la liaison XBee marche.
Sinon → [Station Topcon](04_Raspberry_Pi/Station_Topcon.md) et
[dépannage](06_Calibration_Depannage.md).

---

## En cas de problème

1. Le robot ne répond plus du tout / réception bloquée → **reset du STM32**
   (bouton noir sur la Nucleo). Voir le bug d'overrun UART décrit dans la
   [passation](08_Passation/README.md).
2. Une seule roue tourne, le robot part de travers → problème de seuil moteur,
   voir [calibration](06_Calibration_Depannage.md).
3. La station ne mesure pas → vérifier le port `/dev/ttyUSB0`, le XBee, et que
   la station vise bien le prisme.

> Pour tout comprendre en profondeur, continuez avec la
> [vue d'ensemble](01_Vue_Ensemble/README.md).

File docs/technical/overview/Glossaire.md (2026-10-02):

# Glossaire

Tous les sigles, termes et abréviations rencontrés dans le projet et le code.

| Terme | Signification |
|---|---|
| **ARU** | Arrêt d'Urgence — bouton physique (broche PB14) qui coupe les moteurs |
| **AX12 / Dynamixel** | Servomoteur intelligent (Robotis) commandant le bras du prisme |
| **Backend** | Le serveur Python FastAPI tournant sur la Raspberry Pi |
| **Boustrophédon** | Parcours en serpentin (aller‑retour ligne par ligne) ; cf. labour |
| **CRC** | Code de contrôle d'intégrité d'une trame (ici un simple XOR) |
| **Encodeur en quadrature** | Capteur qui compte la rotation d'une roue (2 voies A/B) |
| **FastAPI** | Framework web Python utilisé pour le backend |
| **Firmware** | Le programme embarqué dans le STM32 (dossier `Core/`) |
| **FL / FR / RL / RR** | Front‑Left / Front‑Right / Rear‑Left / Rear‑Right (les 4 roues) |
| **Frontend** | L'interface web (React) affichée sur la tablette/PC |
| **gon (grade)** | Unité d'angle de la station Topcon (400 gon = 360°) |
| **HAL** | Hardware Abstraction Layer — bibliothèque STMicroelectronics |
| **Hz** | Ici : **angle Horizontal** mesuré par la station (à ne pas confondre avec les hertz) |
| **Mecanum** | Roues à galets inclinés permettant le déplacement omnidirectionnel |
| **MS1AX** | Modèle de station totale robotisée Topcon utilisée |
| **Odométrie** | Estimation de la position (x, y, θ) à partir des encodeurs |
| **Pose** | Position + orientation du robot : (x, y, θ) |
| **PPR** | Pulses Per Revolution — impulsions par tour d'un encodeur |
| **Prisme** | Réflecteur visé par la station pour mesurer angle et distance |
| **Quadrature ×4** | Comptage exploitant les 4 fronts des voies A et B (×4 résolution) |
| **Sabertooth** | Contrôleur de puissance pilotant 2 moteurs DC (mode « Packetized Serial ») |
| **Slew rate / rampe** | Limitation de la variation de consigne par cycle (démarrage doux) |
| **STM32 F446RE** | Microcontrôleur ARM Cortex‑M4 utilisé (carte Nucleo) |
| **Strafe** | Déplacement latéral pur (selon y) sans rotation |
| **Tracking** | Mode où la station suit en continu le prisme en mouvement |
| **TopoBot** | Nom du projet / de l'application Raspberry Pi |
| **Topcon** | Fabricant de la station topographique |
| **UART / USART** | Liaisons série utilisées (Pi↔STM32, STM32↔Sabertooth, STM32↔AX12) |
| **V** | **angle Vertical** mesuré par la station |
| **Waypoint** | Point de passage de la grille (coordonnée x, y à atteindre) |
| **XBee** | Module radio/série reliant la Raspberry Pi à la station Topcon |

## Repères et conventions

- **Repère monde** : repère fixe lié au point de départ. Origine (0,0) = position
  du robot au lancement de la mission. X = avant, Y = gauche.
- **Repère robot** : repère mobile lié au châssis. Le firmware projette les
  erreurs de position du repère monde vers le repère robot pour décider quelles
  vitesses vx/vy commander.
- **Unités** : mètres (m), mètres par seconde (m/s), radians (rad) côté firmware.
  La station Topcon travaille en **gon** (angles) et **mètres** (distances).

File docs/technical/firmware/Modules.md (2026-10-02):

# Modules du firmware — fichier par fichier

Tous les fichiers ci‑dessous sont dans `Core/Src/` (sources) et `Core/Inc/`
(en‑têtes). Pour chaque module : son rôle, ses points d'entrée et les pièges.

---

## `main.c`

Point d'entrée. Responsabilités :
- Initialise les périphériques (générés par CubeMX) : ADC, TIM1‑4/8, UART4/5,
  USART2, GPIO.
- Initialise **TIM6 à la main** (`MX_TIM6_Init`) — base de temps 100 Hz, **non
  générée par CubeMX**.
- Lance les sous‑systèmes : `RobotControl_Init()`, `Protocol_Init()`,
  `AX12_Init()`, active l'alimentation puissance (PA5).
- Boucle `while(1)` : `Protocol_Process()` + `RobotControl_Update()` cadencé par
  le flag `velocity_tick`.
- Contient les callbacks HAL : `HAL_TIM_PeriodElapsedCallback` (TIM6 → flag) et
  `HAL_UART_RxCpltCallback` (USART2 → `Protocol_UART_RxCallback`).

Variables globales partagées : `g_vx`, `g_vy`, `g_wz` (consigne de vitesse
courante), `velocity_tick`.

> ⚠️ Si vous régénérez depuis le `.ioc`, vérifiez que `MX_TIM6_Init`, l'init des
> sous‑systèmes et les callbacks sont **toujours là** (ils sont dans des blocs
> `USER CODE`, donc normalement préservés).

---

## `robot_config.h` ⭐

**Le fichier de réglage central.** Aucune logique, que des `#define`. Regroupe
mapping/polarités encodeurs, UART, AX12, dimensions du robot, calibration
odométrie, gains et limites de l'asservissement, fréquence de boucle.
**Commencez toujours par ici pour régler un comportement.** Voir aussi
[Calibration](../06_Calibration_Depannage.md).

---

## `protocol.c` / `protocol.h`

Dialogue série avec la Raspberry Pi (USART2). Réception en interruption octet
par octet, reconstruction de trame par machine d'état, traitement dans la
boucle principale. Décode les commandes et appelle les modules concernés
(`RobotControl_*`, `Mecanum_*`, `Odom_*`, `AX12_*`), renvoie ACK/DONE/STATUS/ERROR.
Détail complet :
[Protocole de communication](Protocole_Communication.md).

---

## `robot_control.c` / `robot_control.h`

Superviseur de haut niveau : **machine d'états** + **asservissement de
position** (proportionnel pur saturé sur x et y, voir
[README firmware §3.5](README.md#35-stratégie-dasservissement-important)).

Points d'entrée :
- `RobotControl_Init()` — init PID/odom/mecanum, état IDLE.
- `RobotControl_Update()` — appelé à 100 Hz, fait tourner odométrie + ARU +
  asservissement.
- `RobotControl_MoveTo(x, y, θ)` — nouvelle cible (θ ignoré).
- `RobotControl_EmergencyStop()` / `RobotControl_Reset()`.
- `RobotControl_SetGains(...)` / `RobotControl_SetGridLimits(...)`.

Gère aussi : **debounce de l'ARU**, **keepalive Sabertooth** (ré‑envoie un stop
toutes les 500 ms à l'arrêt pour ne pas perdre la liaison), **vitesses
manuelles** en IDLE (via `g_vx`/`g_vy`).

> La vérification des **limites de grille** (`in_grid`) est actuellement
> **désactivée** (`return true;`). À réactiver quand l'odométrie sera fiable.

---

## `odometry.c` / `odometry.h`

Calcule la pose (x, y, θ) à partir des encodeurs. Lecture des compteurs avec
gestion de l'overflow 16 bits, application des polarités, cinématique directe
mecanum, intégration en repère monde (RK2 / point milieu).

⚠️ **Mode `ODOM_REAR_ONLY`** (activé dans `robot_config.h`) : l'odométrie
n'utilise que les 2 encodeurs arrière (RL, RR). Conséquence : **θ est forcé à
0** (avec 2 encodeurs seulement, le calcul d'angle génère une fausse rotation
pendant les déplacements latéraux). C'est acceptable car la rotation n'est ni
commandée ni asservie.

> **Important — réalité matérielle vs commentaires du code** : les commentaires
> de ce fichier et de `robot_config.h` indiquent que FL/FR seraient « hors
> service ». En pratique, **les 4 encodeurs fonctionnent** ; c'est la **carte de
> commande** qui peut, par intermittence, empêcher certains tics d'être comptés.
> D'où la **procédure obligatoire** : vérifier les 4 roues avec
> `test_encoders.py` avant chaque test. Une fois le comptage des 4 roues
> confirmé fiable, `ODOM_REAR_ONLY` peut être repassé à **0** pour exploiter les
> 4 encodeurs et restaurer l'odométrie de θ. Voir
> [passation](../08_Passation/README.md).

Points d'entrée : `Odom_Init`, `Odom_Update(dt)`, `Odom_Reset`,
`Odom_SetPose`, `Odom_GetState`.

---

## `mecanum.c` / `mecanum.h`

Bas niveau moteurs. Convertit une consigne (vx, vy) en vitesses de roues
(cinématique inverse mecanum **sans rotation**), normalise, applique les
polarités de câblage (`POL_*`), et envoie les **paquets Sabertooth** sur UART4.

Cinématique inverse utilisée (translation pure) :
```
w_FL = (vx − vy) / r        w_FR = (vx + vy) / r
w_RL = (vx + vy) / r        w_RR = (vx − vy) / r
```

Points d'entrée : `Mecanum_Init`, `Mecanum_SetVelocity(vx, vy)`,
`Mecanum_Stop`.

> L'envoi est **bloquant** (`HAL_UART_Transmit`) : 4 paquets × 4 octets à
> 9600 bauds ≈ 17 ms. C'est la source du bug d'overrun (voir
> [passation](../08_Passation/README.md)).

---

## `pid.c` / `pid.h`

Régulateur PID générique (anti‑windup + filtrage dérivé). **Dans la version
actuelle, seuls les gains KP sont réellement utilisés** par `robot_control.c`
(les termes I et D sont neutralisés → proportionnel pur). Le module reste
complet et prêt si vous voulez réactiver un vrai PID.

Points d'entrée : `PID_Init`, `PID_Compute(error, dt)`, `PID_Reset`,
`PID_SetGains`.

---

## `ax12.c` / `ax12.h`

Pilote du servo **AX12 Dynamixel** (UART5, 1 Mbps, protocole Dynamixel v1).
Active le couple à l'init, écrit la position et la vitesse cibles.

Points d'entrée :
- `AX12_Init()` — reconfigure UART5 à 1 Mbps, active le couple.
- `AX12_Deploy()` / `AX12_Retract()` — positions par défaut (700 / 200).
- `AX12_DeployCustom(position, vitesse)` — déploiement paramétrable.
- `AX12_SetGoalPosition(id, pos)` / `AX12_SetMovingSpeed(id, speed)`.

---

## Fichiers générés (ne pas modifier sauf nécessité)

| Fichier | Rôle |
|---|---|
| `stm32f4xx_it.c` | Handlers d'interruptions (IRQ). Ajoutez les vôtres dans les blocs USER CODE. |
| `stm32f4xx_hal_msp.c` | Configuration bas niveau des périphériques (horloges, GPIO, NVIC). |
| `system_stm32f4xx.c`, `syscalls.c`, `sysmem.c` | Démarrage système / runtime C. |
| `startup_stm32f446retx.s` | Vecteur d'interruptions / démarrage (assembleur). |
| `Drivers/` | Bibliothèque HAL STMicroelectronics. |

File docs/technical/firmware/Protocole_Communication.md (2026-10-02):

# Protocole de communication Pi ↔ STM32

Liaison **USART2 à 115200 bauds**. Protocole binaire maison, défini des deux
côtés :
- côté STM32 : `Core/Inc/protocol.h` et `Core/Src/protocol.c`
- côté Pi : `topobot/topobot/backend/main.py` (section « PROTOCOLE »)

> Les deux fichiers doivent rester **synchronisés** : si vous ajoutez une
> commande, modifiez les deux.

## Format d'une trame

```
┌────────┬──────┬────────┬───────────────┬──────┐
│ START  │ CMD  │  LEN   │  PAYLOAD...    │ CRC  │
│ 0xAA   │ 1 o. │ 1 o.   │  LEN octets    │ 1 o. │
└────────┴──────┴────────┴───────────────┴──────┘
```

- **START** = `0xAA` (octet de synchronisation).
- **CMD** = code de commande ou de réponse (voir tables ci‑dessous).
- **LEN** = longueur du payload (0 à 63).
- **PAYLOAD** = données (souvent des `float` 32 bits little‑endian).
- **CRC** = XOR de `CMD`, `LEN` et de tous les octets du payload.

```python
def crc(cmd, payload):
    c = cmd ^ len(payload)
    for b in payload:
        c ^= b
    return c & 0xFF
```

## Commandes (Raspberry Pi → STM32)

| Code | Nom | Payload | Effet |
|---|-----|---|---|
| `0x01` | `CMD_MOVE_TO` | x, y, θ (3 floats) | Déplacement asservi vers (x, y). θ ignoré. |
| `0x02` | `CMD_STOP` | — | Arrêt moteurs + retour IDLE. |
| `0x03` | `CMD_RESET_ODOM` | — | Remet pose (x,y,θ) et encodeurs à zéro. |
| `0x04` | `CMD_GET_STATUS` | — | Demande la télémétrie (voir RESP_STATUS). |
| `0x05` | `CMD_SET_GRID` | (max_x, max_y) | Définit les limites de la grille de sécurité. |
| `0x06` | `CMD_SET_GAINS` | gains | Modifie les gains de l'asservissement à chaud. |
| `0x07` | `CMD_SET_VELOCITY` | vx, vy, wz (3 floats) | Vitesse manuelle directe (wz ignoré). |
| `0x10` | `CMD_DEPLOY_PRISM` | *(optionnel : pos u16 + vitesse u16)* | Déploie le prisme (servo AX12). |
| `0x11` | `CMD_RETRACT_PRISM` | — | Replie le prisme. |

> `CMD_DEPLOY_PRISM` accepte un payload optionnel de 4 octets
> `[position(u16 LE)][vitesse(u16 LE)]` pour un déploiement paramétrable ; sans
> payload, il utilise la position/vitesse par défaut de `robot_config.h`.

## Réponses (STM32 → Raspberry Pi)

| Code | Nom | Payload | Sens |
|---|-----|---|---|
| `0xA1` | `RESP_ACK` | (cmd echo) | Commande reçue et acceptée. |
| `0xA2` | `RESP_DONE` | x, y, θ | Mouvement terminé (cible atteinte). |
| `0xA3` | `RESP_STATUS` | structure télémétrie | Réponse à `GET_STATUS`. |
| `0xA4` | `RESP_ERROR` | code erreur (1 o.) | Erreur. |

### Codes d'erreur

| Code | Nom | Cause |
|---|-----|---|
| `0x01` | `ERR_CRC` | CRC invalide ou payload trop court. |
| `0x02` | `ERR_UNKNOWN_CMD` | Commande inconnue. |
| `0x03` | `ERR_BUSY` | Robot occupé. |
| `0x04` | `ERR_OUT_BOUNDS` | Sortie de la grille de sécurité. |
| `0x05` | `ERR_ARU` | Arrêt d'urgence actif. |
| `0x06` | `ERR_AX12` | Échec communication avec le servo. |

## Structure de télémétrie (`RESP_STATUS`)

Format Python : `"<fffiiiiffffffB"` (little‑endian). Champs, dans l'ordre :

| Champ | Type | Description |
|---|---|---|
| vx_cmd, vy_cmd, wz_cmd | float ×3 | Consigne de vitesse courante |
| e1, e2, e3, e4 | int32 ×4 | Compteurs encodeurs bruts (FL, FR, RL, RR) |
| x, y, theta | float ×3 | Pose odométrie (repère monde) |
| vx_meas, vy_meas, wz_meas | float ×3 | Vitesses mesurées (repère robot) |
| state | uint8 | État machine (0=IDLE … 5=ERROR) |

> ⚠️ L'ordre des encodeurs dans la structure correspond aux handles
> `ENC_FL/FR/RL/RR` (TIM4, TIM2, TIM8, TIM3). Comme FL et FR sont hors service,
> e1 et e2 restent figés ; e3 (RL) et e4 (RR) bougent.

## Réception côté STM32 : machine d'état octet par octet

`protocol.c` reçoit **un octet à la fois en interruption**
(`HAL_UART_Receive_IT`) et reconstruit la trame avec une petite machine d'état
(`RX_WAIT_START → RX_WAIT_CMD → RX_WAIT_LEN → RX_DATA → RX_WAIT_CRC`). Quand le
CRC est bon, un flag `frame_ready` est levé et la trame est traitée dans la
boucle principale par `Protocol_Process()` (jamais en interruption).

> **Bug connu lié à ce mécanisme** : si une trame arrive pendant que le STM32
> est occupé à envoyer aux Sabertooth (17 ms), un octet peut être perdu
> (overrun). Détails et contournements dans la
> [passation](../08_Passation/README.md). Plusieurs scripts de test
> (`test_robotf4.py`, `test_robotf5.py`) ont été écrits spécifiquement pour
> éviter ou diagnostiquer ce problème.

## Exemple : envoyer un MOVE_TO depuis Python

```python
import struct, serial
def crc(cmd, p): 
    c = cmd ^ len(p)
    for b in p: c ^= b
    return c & 0xFF
def frame(cmd, p=b""): 
    return bytes([0xAA, cmd, len(p)]) + p + bytes([crc(cmd, p)])

ser = serial.Serial("COM6", 115200, timeout=1)
payload = struct.pack("<fff", 0.10, 0.0, 0.0)   # aller à x=10 cm
ser.write(frame(0x01, payload))                  # CMD_MOVE_TO
```

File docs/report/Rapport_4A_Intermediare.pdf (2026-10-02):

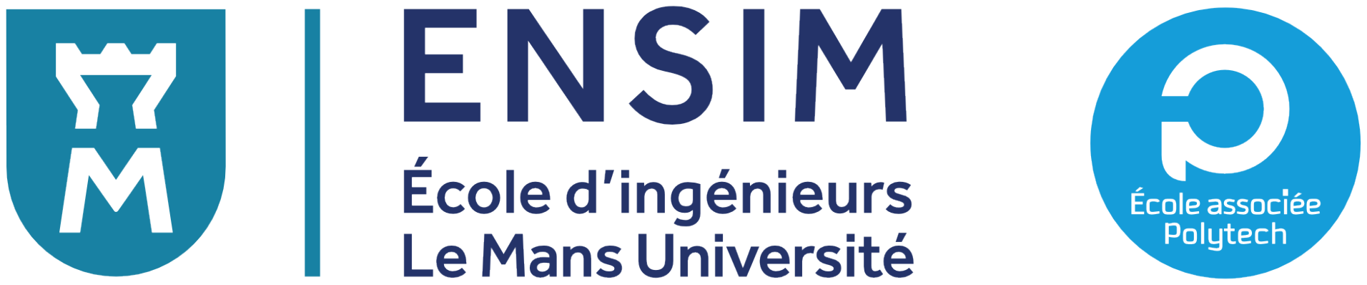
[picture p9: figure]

# Développement d’un robot autonome guidé par station totale topographique pour le contrôle de planéité de surface

Projet 4A

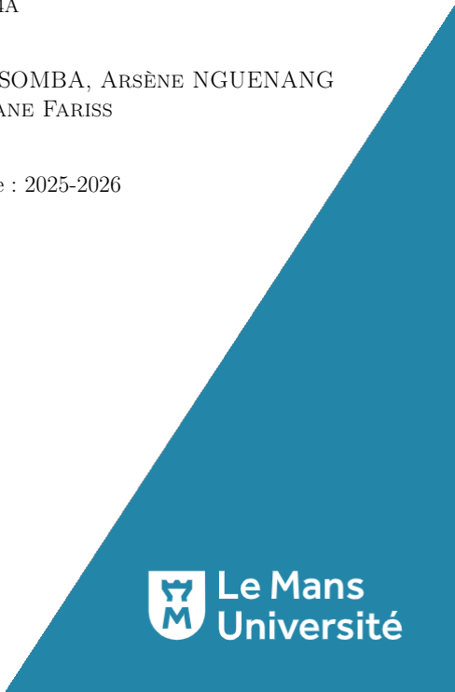
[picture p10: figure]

Benewinde Kontiebo, Michael ESSOMBA, Arsène NGUENANG

YOUKAP, Aymane Fariss

Année universitaire : 2025-2026

Tuteur(s) université :

Matthieu Milharo,
matthieu.milharo@univ-lemans.fr

Résumé
Ce projet porte sur le développement d’un robot mobile destiné à des applications topographiques, et plus particulièrement au contrôle de la planéité des surfaces. L’objectif est d’automatiser le déplacement d’un réflecteur topographique afin de faciliter les mesures, d’améliorer leur répétabilité et de limiter les interventions manuelles.
Le robot repose sur une base mobile à roues Mécanum, permettant des déplacements holonomes. Une chaîne de commande basée sur une Raspberry Pi et des drivers moteurs a permis de valider expérimentalement les déplacements élémentaires. Une communication radio bidirectionnelle a également été mise en œuvre à l’aide de modules XBee pour assurer l’échange de données entre la base mobile et la station de contrôle.
Le projet inclut enfin la conception des cartes électroniques de commande et de puissance, visant à fiabiliser l’intégration matérielle et à préparer l’évolution vers une commande asservie reposant sur un microcontrôleur et des codeurs.

Summary

This project focuses on the development of a mobile robot intended for topographic applications, particularly for surface flatness measurement. The objective is to automate the displacement of a topographic reflector in order to simplify measurement procedures, improve repeatability, and reduce manual handling.
The robot is based on a four-wheel Mecanum platform, allowing holonomic motion. A functional motion control chain using a Raspberry Pi and motor drivers was implemented and experimentally validated for basic movements. A bidirectional radio communication link was also established using XBee modules to enable data exchange between the mobile base and the control station.
The project also includes the design of dedicated control and power electronic boards, aiming to improve system robustness and to prepare future integration of closed-loop control using a microcontroller and encoders.
Robot autonome pour contrôle de planéité | 1

Table des matières

## Table des matières

1 Introduction | 4
2 Organisation du projet | 4
3 Architecture globale du système | 5
4 Conception et Réalisation de la Carte de Commande | 7
5 Conception et commande du déplacement | 9
6 Communication entre la base mobile et la station totale : | 11
7 Tests et validation du système | 13

Table des matières

8 Conception de l’interface de pilotage | 15
9 Conception de l’Interface (IHM) | 16
10 Difficultés rencontrées | 17
11 Conclusion et perspectives | 17
A Annexes | 19
B Diagramme de gantt | 19
C Cahier des Charges Fonctionnel (CDCF) | 19
D Conception électronique et carte PCB | 21
E Déplacement du robot | 25
F Communication des modules XBee | 25
G Interface logicielle | 27
H Codes sources | 29
I Ressources complémentaires | 29

2 Organisation du projet

## 1 Introduction

### 1.1 Contexte général du projet

Dans le cadre du cursus ingénieur, les projets transversaux constituent un support essentiel pour mettre en pratique des compétences techniques acquises tout au long de la formation. Ils permettent de confronter les étudiants à une problématique réelle, nécessitant à la fois une approche méthodique, des choix techniques argumentés et un travail collaboratif.
Le projet présenté dans ce rapport s’inscrit dans ce contexte et porte sur le développement d’un robot mobile destiné à des applications topographiques. Il fait suite à un travail engagé lors d’une année précédente, dont l’objectif était de concevoir une base mobile fonctionnelle capable de se déplacer de manière contrôlée en environnement intérieur.

### 1.2 Problématique et enjeux techniques

Dans les opérations de mesure topographique, et en particulier lors du contrôle de la planéité d’une surface, le déplacement manuel du réflecteur peut s’avérer contraignant et peu répétable. L’utilisation d’un robot mobile vise à automatiser ces déplacements afin de limiter la pénibilité des opérations, d’améliorer la répétabilité des mesures et de faciliter la mise en œuvre de protocoles de mesure structurés.
L’enjeu principal du projet consiste donc à développer un robot capable de se déplacer de manière fiable et maîtrisée, de communiquer avec une station totale topographique et de s’intégrer dans une chaîne de mesure cohérente.

### 1.3 Objectifs du projet

Les objectifs poursuivis dans ce projet peuvent être résumés comme suit :
— concevoir et réaliser les circuits imprimés des parties commande et puissance ;
— assurer une commande fiable des déplacements élémentaires du robot ;
— mettre en place une communication sans fil entre le robot et la station de contrôle ; — valider le fonctionnement global du système par des tests expérimentaux.

### 1.4 Organisation du rapport

Le rapport est structuré de manière à présenter successivement le contexte et l’organisation du projet, l’architecture globale du système, les choix techniques liés au déplacement et à la communication, puis les tests réalisés pour valider le fonctionnement du prototype. Il se conclut par une analyse des limites identifiées et des perspectives d’amélioration.

## 2 Organisation du projet

Le projet a été mené en parallèle sur plusieurs volets techniques (électronique, déplacement, communication et supervision). Pour avancer efficacement, nous avons réparti les

3 Architecture globale du système

tâches par lot, tout en gardant des points réguliers pour recaler l’intégration.

### 2.1 Répartition des tâches

— Carte électronique (PCB) : conception de la carte commande et de la carte puissance, intégration de l’arrêt d’urgence et des protections.
— Déplacement : validation des mouvements élémentaires de la base Mécanum et structuration du pilotage moteur.
— Communication : configuration des modules XBee, scripts d’échange et validation des tests de portée.
— Supervision / traitement : structuration de l’interface et préparation de l’exploitation des données.

### 2.2 Planification

La planification a été suivie à l’aide d’un diagramme de Gantt, présenté en annexe. Il a servi de repère pour fixer des objectifs intermédiaires (Conception de la carte électronique , déplacement, communication, puis intégration).

### 2.3 Approche de travail

Nous avons privilégié une démarche progressive : valider un sous-système, puis passer au suivant, avant de les intégrer ensemble. Cette méthode a été particulièrement utile pour isoler les causes de dysfonctionnement lors des phases de test.

## 3 Architecture globale du système

Cette section présente l’architecture générale du robot en distinguant les aspects matériels et logiciels. L’objectif est de fournir une vue d’ensemble cohérente du système, tout en laissant la possibilité de détailler ultérieurement certains sous-ensembles, notamment la carte électronique et le circuit de puissance, dans les sections dédiées. Pour répondre aux exigences de contrôle de planéité par guidage externe (station totale), nous avons opté pour une architecture modulaire et distribuée. Celle-ci sépare physiquement et logiquement la gestion de l’énergie, le contrôle en temps réel et l’intelligence de navigation.

### 3.1 Architecture Matérielle

L’électronique embarquée est centralisée sur deux cartes électroniques conçues sur mesure (PCB) qui s’interfacent avec les composants du commerce :

— L’unité de gestion d’énergie (Carte Puissance) : Cette carte assure l’interface entre la source d’énergie (batteries) et les consommateurs. Elle conditionne les tensions nécessaires aux différents sous-systèmes.

3 Architecture globale du système

— Régulation : Conversion de la tension batterie en tensions stables (5V, 12V) pour l’électronique de commande via des convertisseurs DC/DC isolés (modules PTN78020W).
— Protection : Elle intègre les éléments de sécurité électrique, notamment les fusibles, les diodes de roue libre et la gestion de l’Arrêt d’Urgence (ARU), garantissant la mise hors tension immédiate des actionneurs en cas de danger. — L’unité de contrôle-commande (Carte Commande) : Cette carte agit comme la "carte mère" du système, interconnectant deux unités de calcul :
— Microcontrôleur (STM32 Nucleo F446RE) : Dédié au "bas niveau". Il gère les tâches temps réel critiques, telles que l’asservissement des moteurs (boucles PID), la lecture des codeurs incrémentaux et la génération des signaux PWM pour les drivers de puissance.
— Nano-ordinateur (Raspberry Pi) : Dédié au "haut niveau". Il assure la communication avec la station totale topographique, gère la trajectoire globale et enregistre les données de planéité.
— L’interface de puissance (Drivers) : La commande des moteurs est déléguée à des contrôleurs de puissance externes (Sabertooth), pilotés par la carte commande, permettant de dissocier les courants forts des signaux logiques.
Remarque sur l’état actuel et la cible : À ce stade, le déplacement du prototype est validé sur une chaîne de commande basée sur Raspberry Pi + pigpio + drivers Sabertooth. Dans la suite du projet, une évolution vers une commande plus précise est prévue via l’intégration d’un microcontrôleur STM32, de codeurs et d’un asservissement PID.

### 3.2 Architecture Logicielle et Flux de Données

L’architecture logicielle reflète la division matérielle et fonctionne selon un modèle maître-esclave :
— Niveau Haut (Raspberry Pi) : Le logiciel embarqué ici (développé en Python) agit comme le chef d’orchestre. Il reçoit les coordonnées (X, Y, Z) de la station totale, calcule l’écart par rapport à la trajectoire idéale et envoie des consignes de vitesse (linéaire et angulaire) au microcontrôleur.
— Niveau Bas (STM32) : Le firmware du microcontrôleur traduit les consignes de vitesse en commandes électriques pour les moteurs. Il surveille en permanence les codeurs pour s’assurer que le robot exécute fidèlement le mouvement demandé, corrigeant les erreurs en temps réel.
La Figure 2 ci-dessous synthétise ces interactions en distinguant la chaîne d’énergie de la chaîne d’information.
Description des flux :
Le diagramme synoptique ci-dessus (Figure 2) illustre les interactions entre les modules :

— Chaîne d’énergie (Flux Rouge) :
La batterie alimente la Carte de Puissance. Celle-ci joue le rôle de distributeur : elle envoie une tension de puissance brute (sécurisée par l’arrêt d’urgence et les

4 Conception et Réalisation de la Carte de Commande

Batterie
Arrêt d’Urgence
(ARU)

Carte Puissance
(Régulation
& Protec.)

STM32 Nucleo
(Contrôle
Bas Niveau)

Raspberry Pi
(Intelligence)

Carte Commande

Drivers Moteurs
(Sabertooth)

Moteurs CC
+ Codeurs

Station Totale
Topographique | Alim Puissance

UART Wifi/Radio 5V / 12V

Codeurs

Figure 2 – Diagramme synoptique de l’architecture du robot. Les flèches rouges représentent l’énergie, les flèches bleues les informations.

fusibles) vers les drivers moteurs (Sabertooth) et convertit cette énergie en tensions régulées (5V, 12V) pour alimenter la Carte de Commande (Raspberry Pi et STM32).
— Chaîne d’information (Flux Bleu) :
— La Station Totale transmet la position du robot au Raspberry Pi.
— Le Raspberry Pi calcule la consigne de vitesse et la transmet au STM32 Nucleo via une liaison série (UART).
— Le STM32 pilote les Drivers Sabertooth (via PWM) pour faire tourner les moteurs.
— En retour, les Codeurs des moteurs informent le STM32 du déplacement réel effectué, permettant une correction en boucle fermée (asservissement).

## 4 Conception et Réalisation de la Carte de Commande

Cette section détaille le processus de développement de la carte électronique centrale, depuis la schématisation initiale jusqu’au routage du circuit imprimé (PCB). L’objectif était de passer d’un montage prototypique prit à EnsimElec à une solution robuste, capable de commander et résister aux vibrations du robot mobile.

### 4.1 Évolution du Schéma Électronique

La conception s’est déroulée en deux phases distinctes sous le logiciel de CAO électronique KiCad.

### 4.1.1 Le Schéma de Base (Prototypage)

Nous sommes partis d’une architecture minimaliste centrée sur le microcontrôleur STM32 Nucleo F446RE. Ce premier jet a permis de valider les assignations des broches (pinout) pour les périphériques essentiels : les signaux PWM pour les moteurs et les entrées pour les codeurs (voir Figure 6).

4 Conception et Réalisation de la Carte de Commande

### 4.1.2 Le Schéma Final et Choix des Composants

Pour garantir la fiabilité des signaux et faciliter l’assemblage, le schéma a été enrichi et finalisé comme illustré en Figure 3.

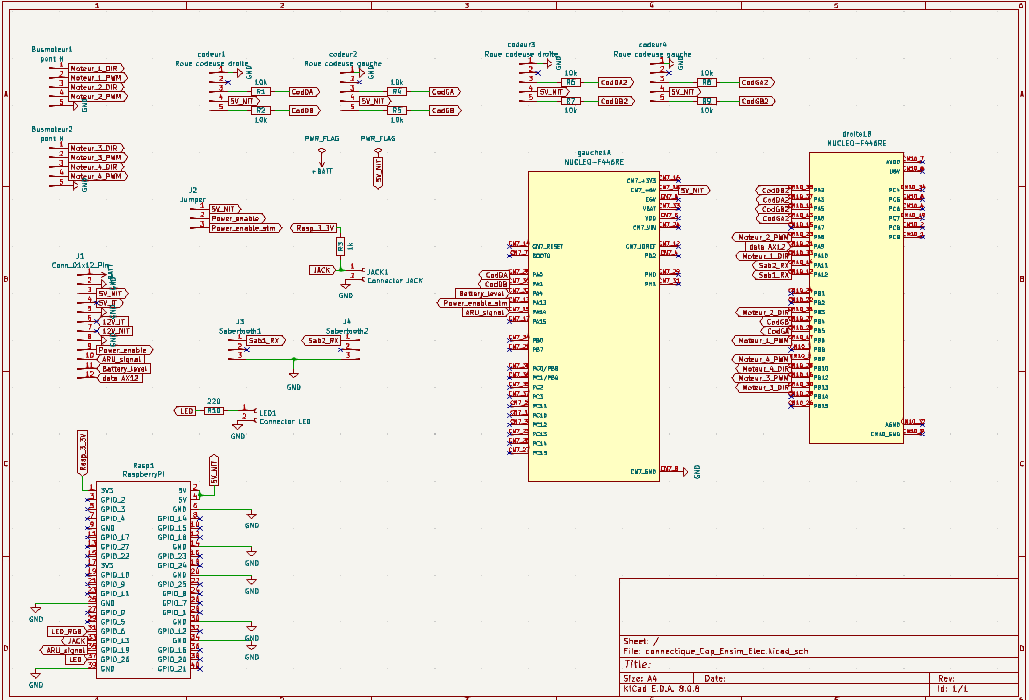
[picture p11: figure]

Figure 3 – Schématique final intégrant les interfaces et protections.

Les améliorations principales par rapport au schéma de base sont les suivantes :
— Intégration des interfaces : Ajout de connecteurs dédiés (headers 2.54mm) pour accueillir directement le Raspberry Pi (via le connecteur GPIO 40 broches) et les drivers moteurs (Sabertooth), éliminant ainsi le câblage volant propice aux faux contacts.
— Conditionnement des signaux : Ajout de résistances de tirage (pull-up) de 10kΩ (R1 à R9) sur les lignes des codeurs incrémentaux. Ces composants sont indispensables pour assurer un niveau logique stable (état haut) lorsque les sorties des codeurs sont en collecteur ouvert.
— Connectique : Standardisation des connecteurs pour les capteurs et l’alimentation afin de faciliter la maintenance future.

### 4.2 Configuration des Règles de Conception (Design Rules)

Avant d’entamer le routage physique, nous avons défini les contraintes de fabrication dans les options du circuit imprimé de KiCad. Ces règles garantissent que le PCB respecte les capacités de production et les exigences électriques du projet (voir Figure 8).

5 Conception et commande du déplacement

Nous avons défini des classes de réseaux spécifiques pour adapter la géométrie des pistes à leur fonction, comme résumé dans le Tableau 1.

Table 1 – Règles de routage définies pour le PCB.

Type de Signal | Largeur | Justification
Alimentation (5V, GND) | 0.8mm | Minimiser la chute de tension et l’échauffe-ment dû au courant consommé par le Rasp-berry Pi et le STM32.
Signaux (UART, GPIO) | 0.5mm | Compromis entre densité de routage et robus-tesse mécanique (pistes moins fragiles lors du soudage manuel).

### 4.3 Routage du Circuit Imprimé (PCB)

Le routage a été réalisé sur une carte double face. La Figure 11 présente le résultat final du typon.
La stratégie de placement a suivi plusieurs critères clés :
— Placement des Connecteurs : Les connecteurs de la carte Nucleo et du Raspberry Pi ont été positionnés de manière à respecter l’empreinte physique des cartes filles, assurant un empilement mécanique stable et compact.
— Topologie des Pistes : Les pistes d’alimentation de 0.8mm ont été tracées en priorité pour assurer une distribution efficace de l’énergie. Les pistes de signaux de 0.5mm ont ensuite été routées en minimisant la longueur des trajets et le nombre de vias (trous de passage inter-couches) pour préserver l’intégrité du signal.
— Plan de Masse : Un plan de masse (GND) a été appliqué sur les zones vides des deux faces, améliorant l’immunité aux parasites électromagnétiques (CEM) et facilitant le retour de courant.

## 5 Conception et commande du déplacement

Cette section présente les principes retenus pour assurer le déplacement du robot, ainsi que les choix de commande mis en œuvre. L’objectif n’est pas de détailler l’intégralité des implémentations logicielles ou des essais réalisés, mais de fournir une synthèse des mécanismes de déplacement validés expérimentalement. Les aspects techniques détaillés, incluant le câblage, les versions de code et les procédures de diagnostic, sont regroupés dans la documentation technique fournie en annexe.

### 5.1 Principe du déplacement holonome

Le robot repose sur une base mobile à quatre roues Mécanum, permettant un déplacement dit holonome. Grâce à l’orientation spécifique des galets montés sur chaque roue,

5 Conception et commande du déplacement

cette architecture autorise des translations dans toutes les directions du plan, ainsi que des rotations sur place, sans nécessiter de changement préalable de l’orientation du châssis. Ce type de déplacement présente un intérêt particulier pour les applications de mesure et de positionnement, où la capacité à effectuer des ajustements latéraux fins constitue un avantage par rapport à une base différentielle classique.

### 5.2 Chaîne de commande du mouvement

La génération des commandes de déplacement est assurée par une Raspberry Pi, utilisée comme unité de calcul embarquée. Celle-ci produit des signaux de commande de type PWM, interprétés par des contrôleurs moteurs de type Sabertooth chargés d’alimenter les moteurs électriques.
Les signaux envoyés suivent un protocole de type radiocommande, avec des largeurs d’impulsion comprises entre 1000 µs à 2000 µs. Une valeur neutre, typiquement fixée à 1500 µs, correspond à l’arrêt du moteur, tandis que des valeurs supérieures ou inférieures induisent une rotation dans un sens ou dans l’autre. Ce mode de commande simple permet une mise en œuvre rapide et fiable des déplacements élémentaires.

### 5.3 Déplacements élémentaires validés

Les essais réalisés ont permis de valider un ensemble de mouvements élémentaires, servant de briques de base pour des trajectoires plus complexes. Ces mouvements reposent sur des combinaisons cohérentes de commandes appliquées aux quatre roues.
— Translation avant et arrière : application de consignes identiques sur l’ensemble des roues.
— Rotation sur place : application de consignes opposées entre le côté gauche et le côté droit du robot.
— Translation latérale : application de consignes croisées, exploitant la géométrie spécifique des roues Mécanum.

Table 2 – Principe de combinaison des commandes pour les déplacements élémentaires.

Mouvement | Avant gauche | Avant droite | Arrière gauche | Arrière droite
Translation avant Translation arrière Rotation gauche Rotation droite Translation latérale gauche Translation latérale droite | + --+ -+ | + -+ -+ - | + --+ + - | + -+ --+

Les signes indiquent uniquement le sens relatif de rotation et non une valeur numérique précise de commande.

6 Communication entre la base mobile et la station totale :

### 5.4 Organisation logicielle de la commande

La commande du déplacement est structurée autour de deux scripts principaux : un script de contrôle manuel et un script de commande autonome. Le premier permet de piloter le robot en temps réel à l’aide du clavier, facilitant les phases de test, de réglage et de diagnostic. Le second exécute automatiquement des séquences de mouvements prédéfinies, reposant sur des temporisations, afin de reproduire des déplacements de manière répétable. Dans les deux cas, l’envoi des signaux moteurs est centralisé au sein de fonctions communes, ce qui simplifie la maintenance du code et limite les erreurs lors des modifications ultérieures. Les implémentations complètes sont volontairement exclues du corps du rapport et présentées en annexe.

### 5.5 Limites actuelles et perspectives

La stratégie de commande mise en place constitue une base fonctionnelle pour le déplacement du robot, mais présente plusieurs limites identifiées :
— l’absence d’asservissement en boucle fermée, la commande reposant uniquement sur des temporisations ;
— une dépendance au câblage réel et au sens de rotation des moteurs, nécessitant une phase de validation expérimentale ;
— une précision de déplacement sensible aux conditions de sol et aux variations mécaniques.
Ces limites ouvrent des perspectives d’amélioration, notamment par l’intégration d’encodeurs, la mise en place d’un asservissement de type PID et l’exploitation de retours capteurs pour améliorer la précision et la robustesse du déplacement.

## 6 Communication entre la base mobile et la station totale :

L’objectif de ce module est d’établir un lien de communication fiable entre le robot (base mobile) et la station totale. Cette liaison radio doit permettre :
— L’échange de données (coordonnées, commandes, validations des mesures).
— Positionnement de manière successive et automatique le réflecteur topographique sur une grille recouvrant la zone à explorer.
— Une communication bidirectionnelle (Full Duplex) sur une portée suffisante pour les mesures terrain.

### 6.1 Choix technologique :

Au cours de l’année précédente, la solutionsde communication radio avaient déjà été fixée. Il existe plusieurs protocoles standard pour la communication radio tels que LoRa, Zigbee ou les modems propriétaires Satelline. Nous avons réalisé une comparaison technique pour identifier la solution la plus adaptée à notre cahier des charges.

6 Communication entre la base mobile et la station totale :

Table 3 – Comparatif des modules de communication

Caractéristiques | XBee S2C | SATELLINE - 2ASXE | LoRa SX1278
Fréquence | 2.4 GHz | 370–470 MHz | 433–915 MHz
Portée | 60–90 m (Int) / 1.2 km (Ext) | 4 à 40 km | Jusqu’à 10 km
Débit | RF 250 kbps / Série 1 Mbps | 1200–4800 bps | Jusqu’à 300 kbps
Consommation | Faible (Tx : 33–45 mA) | Moyenne (Tx : 6.6 VA) | Très faible (Tx : 20–120 mA)
Avantages | Grande fréquence, bon débit, faible consommation | Très grande portée | Grande portée, faible consommation
Inconvénients | Portée plus faible | Débit faible | Nécessite antenne externe

### 6.1.1 Justification du choix

Notre choix s’est finalement porté sur le module XBee S2C pour les raisons suivantes : Tout d’abord, le modem SATELLINE-2ASXE possède un débit trop faible (1200-4800 bps), ce qui est critique pour la réactivité de notre projet ; il fut donc exclu. Le choix s’est alors resserré entre le XBee et le LoRa SX1278.
Bien que LoRa SX1278 offre une portée exceptionnelle, celle-ci est surdimensionnée par rapport aux besoins du robot (qui évolue à vue de la station). Le module XBee respecte déjà les conditions du cahier des charges et possède un débit série bien plus important ainsi leur facilité d’implimentation, facilitant le transfert de données. De plus, les modules XBee étaient déjà fournis par l’école, évitant l’achat de composants supplémentaires nécessaires au fonctionnement du LoRa SX1278.
Nous utilisons donc deux cartes XBee S2C (une sur le robot, l’autre sur la station totale) pour assurer la communication bidirectionnelle entre les deux cartes, à la fois en mode émetteur et récepteur (Full Duplex).

### 6.2 Mise en œuvre et Configuration (XCTU)

### 6.2.1 Matériel utilisé

L’architecture matérielle repose sur les éléments suivants :
— Deux cartes xbee receiver board permettant de connecter les modules.
— une Carte Raspberry Pi 4 pour exécuter le programme embarqué et gérer l’interface de communication via GPIO. Autres composantes inclus :(Voir annexe 6)

### 6.2.2 Configuration logicielle

La première étape est de configurer les modules XBee via le logiciel Digi XCTU. Pour assurer une communication transparente (Mode AT), il faut aussi fixer les paramètres suivants dans les deux modules pour s’assurer que les deux cartes sont sur le même channel (sinon risque d’interférer avec d’autres XBees).

7 Tests et validation du système

Table 4 – Paramètres de configuration XBee

Paramètre | Valeur Configurée | Justification
Baud Rate | 9600 | Standard fiable pour distances <100m.
Data Bits | 8 | Standard pour le texte ASCII
Parity | None | XBee gère sa propre correction d’erreurs
Stop Bits | 1 | Suffisant pour la synchronisation
Flow Control | None | Pas nécessaire vu le faible volume de données
Channel (CH) | C (ou 0x0C) | Doit être identique sur les deux modules
PAN ID (ID) | B332 | Identifiant réseau unique pour l’appairage
CE | End Device | Configuration point-à-point simple

Note : Les adresses DL (Destination Low) et MY (Source Address) ont été croisées entre les deux modules (Module 1 : DL=2, MY=1 / Module 2 : DL=1, MY=2) pour permettre le ciblage. Voir annexe pour les captures d’écran de la configuration XCTU.

## 7 Tests et validation du système

Cette section présente les tests réalisés afin de valider le fonctionnement global du robot. Les essais ont porté à la fois sur le déplacement de la base mobile et sur la communication sans fil, dans une logique de montée progressive en intégration. L’objectif principal était de vérifier la cohérence et la fiabilité du système dans des conditions représentatives d’utilisation, et non d’optimiser ses performances.

### 7.1 Méthodologie de test

Les tests ont été menés par étapes, en commençant par la validation indépendante des sous-systèmes, avant de passer à des essais intégrés. Cette démarche progressive a permis d’identifier plus facilement l’origine des dysfonctionnements observés et de corriger les problèmes au fur et à mesure.
Concernant la communication, le protocole de test retenu a été le suivant :
— test de communication radio entre deux modules XBee connectés à des PC, à l’aide du logiciel XCTU ;
— test de communication entre un PC et une Raspberry Pi via une interface série USB, en s’appuyant sur des scripts Python ;
— intégration finale avec utilisation directe de l’interface UART de la Raspberry Pi via les ports GPIO ;
— tests de portée en environnement intérieur et extérieur.
En parallèle, les déplacements élémentaires du robot ont été testés afin de vérifier la bonne exécution des commandes motrices.

7 Tests et validation du système

### 7.2 Validation du déplacement

Les premiers essais ont porté sur la validation des déplacements élémentaires de la base mobile. Les mouvements d’avance, de recul, de rotation sur place et de translation latérale ont été testés séparément. Plusieurs ajustements ont été nécessaires, notamment en lien avec le câblage et le sens de rotation des moteurs.
Une fois ces corrections effectuées, les déplacements attendus ont pu être reproduits de manière fiable sur une surface plane. Ces essais ont permis de confirmer la cohérence de la commande des roues Mécanum ainsi que la validité des combinaisons de signaux utilisées pour piloter les moteurs.

### 7.3 Validation de la communication

La communication radio entre les deux modules XBee (l’un connecté au PC, l’autre à la Raspberry Pi) a été validée dans un premier temps à l’aide du logiciel XCTU. Les échanges de messages ont confirmé le bon appairage des modules et la pertinence des paramètres de configuration retenus.
Lors de l’intégration de la Raspberry Pi, des scripts Python ont été développés afin de permettre l’envoi et la réception de messages en temps réel. Les messages transmis depuis le PC s’affichaient correctement dans le terminal de la Raspberry Pi, et inversement, confirmant le bon fonctionnement de la communication série.
Un comportement indésirable a toutefois été observé lors de l’utilisation de la console XCTU, avec une fragmentation des messages lors de la saisie manuelle. Ce problème a été corrigé par le développement d’un script Python dédié côté PC, basé sur la bibliothèque pyserial, permettant l’envoi de messages complets et stables.
L’étape finale a consisté à utiliser directement l’interface UART de la Raspberry Pi via les ports GPIO (RX sur GPIO 15, TX sur GPIO 14), en remplaçant le port /dev/ttyUSB0 par /dev/serial0. Cette intégration a permis de supprimer le lien USB sans dégrader la qualité de la communication, les échanges restant fluides et exploitables.

### 7.4 Tests de portée et intégration globale

Des tests de portée ont été réalisés dans l’enceinte de l’ENSIM :
— en intérieur (couloirs), une portée comprise entre 90 et 100 mètres ;
— en extérieur (zone arborée), une portée d’environ 80 mètres.
Ces résultats sont cohérents avec les spécifications des modules XBee S2C et suffisants pour les besoins du projet. Une fois la communication établie, les commandes envoyées à distance ont permis de déclencher correctement les déplacements du robot, validant ainsi l’intégration entre la communication et la commande motrice.
Quelques instabilités logicielles ponctuelles ont été observées lors de tests prolongés, nécessitant parfois un redémarrage des scripts. Ces comportements n’ont toutefois pas remis en cause le fonctionnement global du système.

8 Conception de l’interface de pilotage

## 8 Conception de l’interface de pilotage

### 8.1 Objectifs de l’interface

L’interface doit répondre aux besoins suivants :
— Accessibilité : Être utilisable sur tablette ou ordinateur portable directement sur le terrain.
— Clarté : Guider l’utilisateur dans la procédure de mise en station (souvent complexe en topographie).
— Supervision : Offrir un retour visuel immédiat sur l’état du robot et de l’instrument de mesure.
— Gestion des données : Permettre une validation rapide des points mesurés et leur export.

### 8.2 Choix de l’architecture Web

Le choix s’est porté sur une architecture Web App. Contrairement à une application native, cette solution offre une compatibilité universelle (Cross-platform) sans nécessité d’installation lourde sur les terminaux des géomètres. Le design a été conçu via l’outil Figma pour itérer rapidement sur l’expérience utilisateur.

### 8.3 Architecture de Déploiement Embarqué

L’application "TopoBot Manager" est conçue pour être hébergée directement sur le robot, garantissant une autonomie totale sur le terrain, même en l’absence de couverture réseau 4G/5G.

Le Raspberry Pi comme Serveur Central

Le cœur numérique du robot est un nano-ordinateur Raspberry Pi (modèle 4 ). Il assure un double rôle :
— Contrôle Robotique : Il exécute les nœuds ROS (Robot Operating System) qui pilotent les moteurs de la base holonome et gèrent les capteurs.
— Serveur Web : Il héberge le serveur HTTP (via Nginx ) qui distribue l’interface utilisateur développée.

Mode Point d’Accès (Hotspot)

Pour permettre la connexion de la tablette ou du PC de l’opérateur, le Raspberry Pi sera configuré en mode Point d’Accès Wi-Fi (Access Point). Concrètement, le robot génère son propre réseau Wi-Fi local (ex : "TopoBot_Network"). L’opérateur s’y connecte et accède à l’application via une adresse IP locale statique dans son navigateur web. Cette architecture assure une faible latence dans la transmission des ordres et du flux vidéo, tout en s’affranchissant des infrastructures réseaux externes.

9 Conception de l’Interface (IHM)

## 9 Conception de l’Interface (IHM)

L’application se décompose en quatre modules fonctionnels distincts correspondant au flux de travail typique d’une mission topographique.

### 9.1 Module de Connexion et Statut

La première étape critique est l’établissement de la communication entre le poste de contrôle, le robot (base mobile Lynxmotion A4WD3) et l’instrument topographique (Station Totale).
Comme illustré sur la Figure 16, l’interface vérifie les prérequis (tension, portée radio) avant de permettre l’initiation de la connexion, garantissant la sécurité du système avant tout mouvement.

### 9.2 Configuration de la Mission

L’un des défis majeurs était de simplifier la définition de la zone de travail. Nous avons opté pour une approche paramétrique simple : définition de la largeur (X) et de la longueur (Y ) de la zone, ainsi que du pas de mesure.
Un panneau d’instructions (visible à droite de la Figure 17) rappelle à l’opérateur les étapes physiques nécessaires (positionnement à l’origine 0, 0, orientation), réduisant ainsi les erreurs de référentiel terrain.

### 9.3 Supervision Temps Réel

Une fois la mission lancée, l’opérateur bascule sur le tableau de bord de supervision. Cette vue est centrale pour la sécurité et le contrôle qualité.
Cette interface (Figure 18) regroupe :
— Une visualisation graphique de la grille avec l’état des points (mesuré/à faire).
— Une barre de progression globale.
— Un journal d’activité (logs) pour le débogage en direct.
— Un bouton "Arrêt d’urgence" rouge, accessible en permanence.

### 9.4 Analyse et Export des Résultats

Enfin, la mission terminée, l’interface présente une synthèse des données topographiques (X, Y, Z).
L’écran de résultats (Figure 19) permet de vérifier la cohérence des mesures (Ecart Max Z) et d’exporter le nuage de points au format CSV pour un post-traitement dans des logiciels de DAO/CAO habituels des géomètres.

11 Conclusion et perspectives

## 10 Difficultés rencontrées

Au cours du développement du robot mobile, plusieurs difficultés techniques ont été rencontrées, principalement liées à la communication, au câblage électrique et à la commande du déplacement. Ces problèmes ont nécessité de nombreuses phases de test et de diagnostic avant d’aboutir à un fonctionnement stable du système.

### 10.1 Difficultés liées à la communication

La mise en place de la communication entre la Raspberry Pi, les modules XBee et le poste de contrôle s’est révélée délicate. Des instabilités ont été observées au niveau de la connexion réseau, notamment pour l’accès distant à la Raspberry Pi via SSH. L’absence d’interface écran sur le robot a également compliqué l’identification de son adresse IP lors des phases de configuration et de test.
Par ailleurs, certains scripts Python fonctionnels lors des premiers essais se sont avérés instables lors de tests ultérieurs, nécessitant des vérifications régulières de l’environnement logiciel et des interfaces de communication série.

### 10.2 Difficultés liées au câblage et à l’alimentation

Des erreurs de câblage ont été rencontrées lors de l’intégration de l’électronique embarquée, notamment des inversions de polarité ayant conduit à des dysfonctionnements sur la carte de puissance. L’absence initiale d’un interrupteur principal a également rendu la gestion de l’alimentation plus contraignante lors des phases de test.
Ces difficultés ont mis en évidence l’importance d’une identification claire des connexions et d’une sécurisation accrue de la chaîne d’alimentation.

### 10.3 Difficultés liées au déplacement du robot

Les premiers essais de déplacement ont révélé des comportements asymétriques de la base mobile, avec des roues ne réagissant pas correctement aux commandes. La diversité des causes possibles (câblage, configuration des GPIO, logique logicielle) a complexifié le diagnostic.
De plus, plusieurs ajustements successifs du code ont été nécessaires afin d’obtenir une correspondance correcte entre les consignes de déplacement et le mouvement réel du robot, en particulier pour les translations latérales et les rotations.
Ces difficultés ont souligné la forte dépendance entre le câblage physique, le sens de rotation des moteurs et l’implémentation logicielle.

## 11 Conclusion et perspectives

Ce projet a permis de mettre en place une base mobile à roues Mécanum et d’en valider les déplacements élémentaires (translation, rotation et déplacement latéral) à partir d’une chaîne de commande fonctionnelle basée sur une Raspberry Pi, la bibliothèque

Références

pigpio et des drivers Sabertooth. Les tests menés ont également permis de valider une communication radio exploitable via des modules XBee, ainsi qu’une première intégration entre la communication et la commande motrice.
Parallèlement, la conception des cartes électroniques constitue un objectif central du projet. Les schémas et la modélisation des cartes commande et puissance posent les bases d’une intégration plus propre et plus robuste de l’électronique embarquée, notamment en matière de distribution d’énergie, de protection et de sécurité.
Les prochaines étapes portent sur trois axes principaux :
— la fabrication (impression) et l’assemblage des cartes électroniques afin de passer d’une conception à une intégration matérielle complète ;
— la fiabilisation de la chaîne logicielle et des tests d’intégration sur des durées plus longues ;
— l’amélioration de la précision du déplacement par l’intégration d’un STM32, de codeurs et la mise en place d’un asservissement PID, afin de limiter la dépendance aux conditions de sol et aux effets de glissement.
Ces évolutions permettront d’aboutir à une plateforme plus robuste et mieux adaptée aux tests terrain, en vue de l’interfaçage complet avec la station totale et de l’automatisation d’un parcours de mesure.

## Références

[1] Documentation technique du robot Mécanum (documents internes), Groupe ENSIM, 2025–2026.
[2] Wikipédia, Roue holonome. https://fr.wikipedia.org/wiki/Roue_holonome
[3] Lynxmotion, A4WD3 Mecanum Rover Kit. https://wiki.lynxmotion.com/info/wiki/lynxmotion/view/rover-kits/a4wd3-mecanum/ (https://wiki.lynxmotion.com/info/wiki/lynxmotion/view/rover-kits/a4wd3-mecanum/)
[4] Digi International, XBee S2C Documentation. https://www.digi.com/products/embedded-systems/digi-xbee (https://www.digi.com/products/embedded-systems/digi-xbee)
[5] Borenstein, J., Everett, H. R., Feng, L., Navigating Mobile Robots : Systems and Techniques, A K Peters, 1996.
[6] Choi, J., Lee, J., Kinematic Analysis of Mecanum Wheel Drive, Journal of Mechanical Science and Technology, Vol. 26, No. 11, 2012.
[7] Bolton, W., Mechatronics : Electronic Control Systems in Mechanical and Electrical Engineering, Pearson Education, 6th Edition, 2015.
[8] Sicard, G., De Fornel, B., Électronique embarquée – Applications industrielles, Dunod, 2018.
[9] Rappaport, T. S., Wireless Communications : Principles and Practice, Prentice Hall, 2nd Edition, 2002.

C Cahier des Charges Fonctionnel (CDCF)

## A Annexes

## B Diagramme de gantt

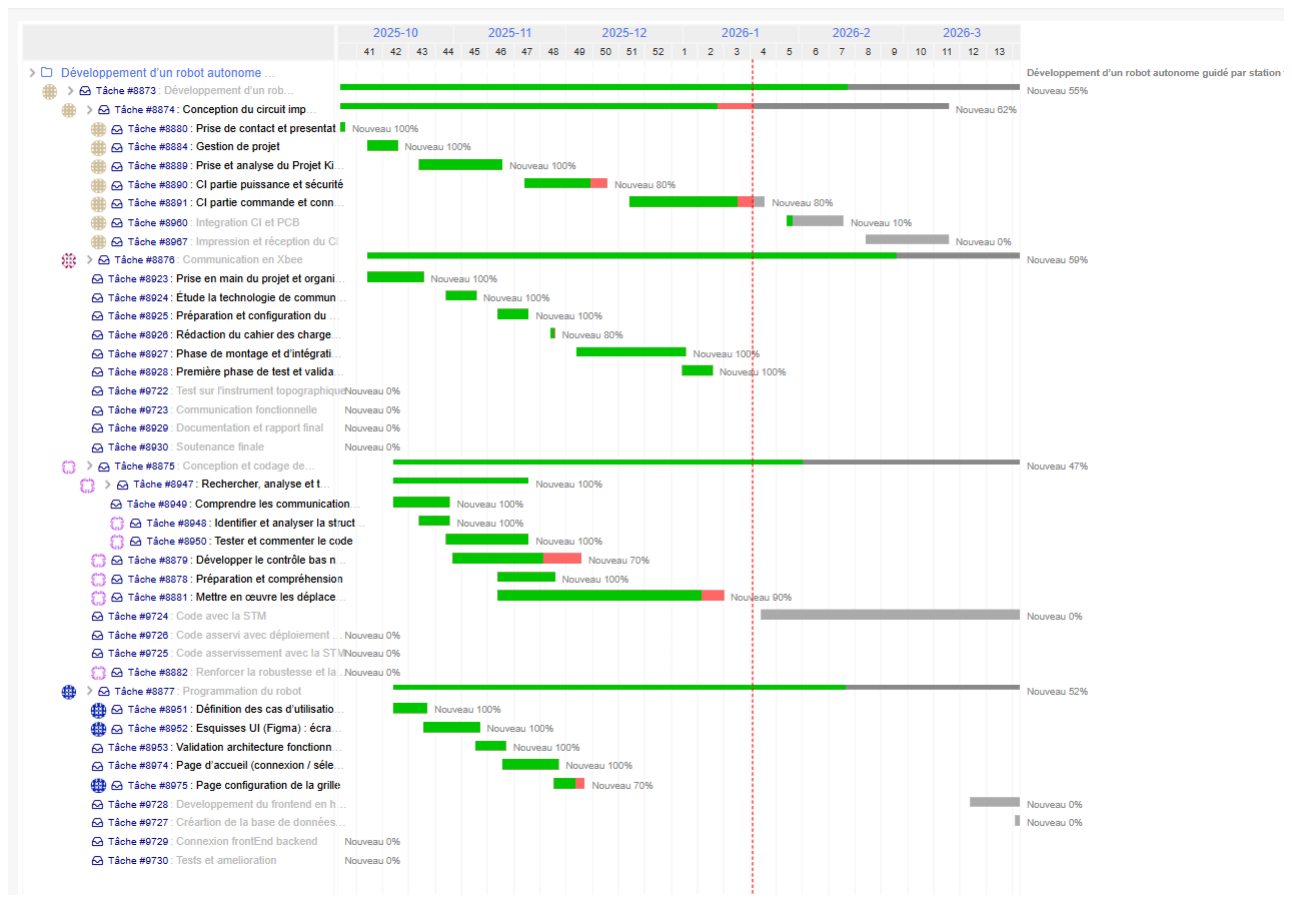
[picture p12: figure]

Figure 4 – Diagramme de Gantt.

## C Cahier des Charges Fonctionnel (CDCF)

C.1 Analyse du besoin

Contrairement aux itérations précédentes, cette année met l’accent sur une navigation en intérieur (type couloirs de l’ENSIM) et sur une ergonomie accrue via des interfaces mobiles.
Les fonctionnalités attendues sont les suivantes :
1. Navigation autonome : Le robot doit parcourir une zone non planifiée, délimitée
| par des marquages ou barrières, tout en évitant les obstacles statiques et les vides (escaliers, estrades).
2. Prise de mesure : Positionnement automatique d’un réflecteur sphérique (∅ 40mm)
| au sol sur les nœuds d’une grille virtuelle.
3. Interface utilisateur : Configuration et pilotage accessibles tout public via tablette
| ou smartphone.
4. Indépendance énergétique : Couverture d’une surface de 50m × 50m avec un
| pas de mesure de 0.5m sans recharge intermédiaire.

C Cahier des Charges Fonctionnel (CDCF)

5. Autonomie opérationnelle : Le robot doit ordonner la mesure à la station totale et stocker les données récupérées. On peut ainsi poser le nouveau diagramme des interacteurs..

Fonctions principales et contraintes :

FP1 Déplacer et orienter le réflecteur topographique sur la zone de mesure ;
FC1 Communiquer avec la station totale (commande de mesure, récupération 3D) ; FC2 Permettre la configuration et le suivi via interface mobile (Tablette/Smartphone) ; FC3 Assurer l’autonomie énergétique pour la couverture de la zone (50m × 50m) ;
FC4 S’adapter à l’environnement intérieur (détection des obstacles, adhérence sol plat, détection des vides) ;
FC5 Respecter les normes.
(Sol intérieur) Station totale | Robot autonome | Environnement Normes
Utilisateur Topographique | | | FC12345 FP1 | (Vides, Escaliers) Source d’énergie
(Lynxmotion | + | Réflecteur)

Zone à explorer

(Tablette/Smartphone)

(Batterie)

Figure 5 – Diagramme des fonctions techniques

D Conception électronique et carte PCB Tableau des critères et niveaux d’exigence

Ref | Fonctions | Critères d’appréciation | Niveau d’exigence | Flex.
FP1 | Déplacer et orienter le réflecteur sur la zone | Surface de couverture Pas de la grille Type de réflecteur Orientation | 50m × 50m 0.5m (configurable) Sphérique ∅40mm Vers la station | ◦ ±5
FC1 | Communiquer avec la station totale | Liaison Données échangées Portée | Radio (Xbee S2C) Ordre mesure + Co-ordonnées XYZ Couverture de la zone
FC2 | Interface de configuration et suivi | Support Accessibilité | Tablette ou Smart-phone Utilisateur
FC3 | Assurer l’autonomie énergétique | Durée de fonctionnement Batterie | Couverture complète 50m × 50m Rechargeable
FC4 | S’adapter à l’environnement intérieur | Type de sol Sécurité | Intérieur (Plan) Détection des obs-tacle/Détection des vides/escaliers
FC5 | Respecter les normes | Homologation Normes environnementale | Toutes

Table 5 – Cahier des charges fonctionnel

## D Conception électronique et carte PCB

D.1 Schémas électriques

Cette section regroupe les schémas électriques principaux de la carte de commande et de la carte de puissance, utilisés pour la conception et la validation du fonctionnement électrique du système.

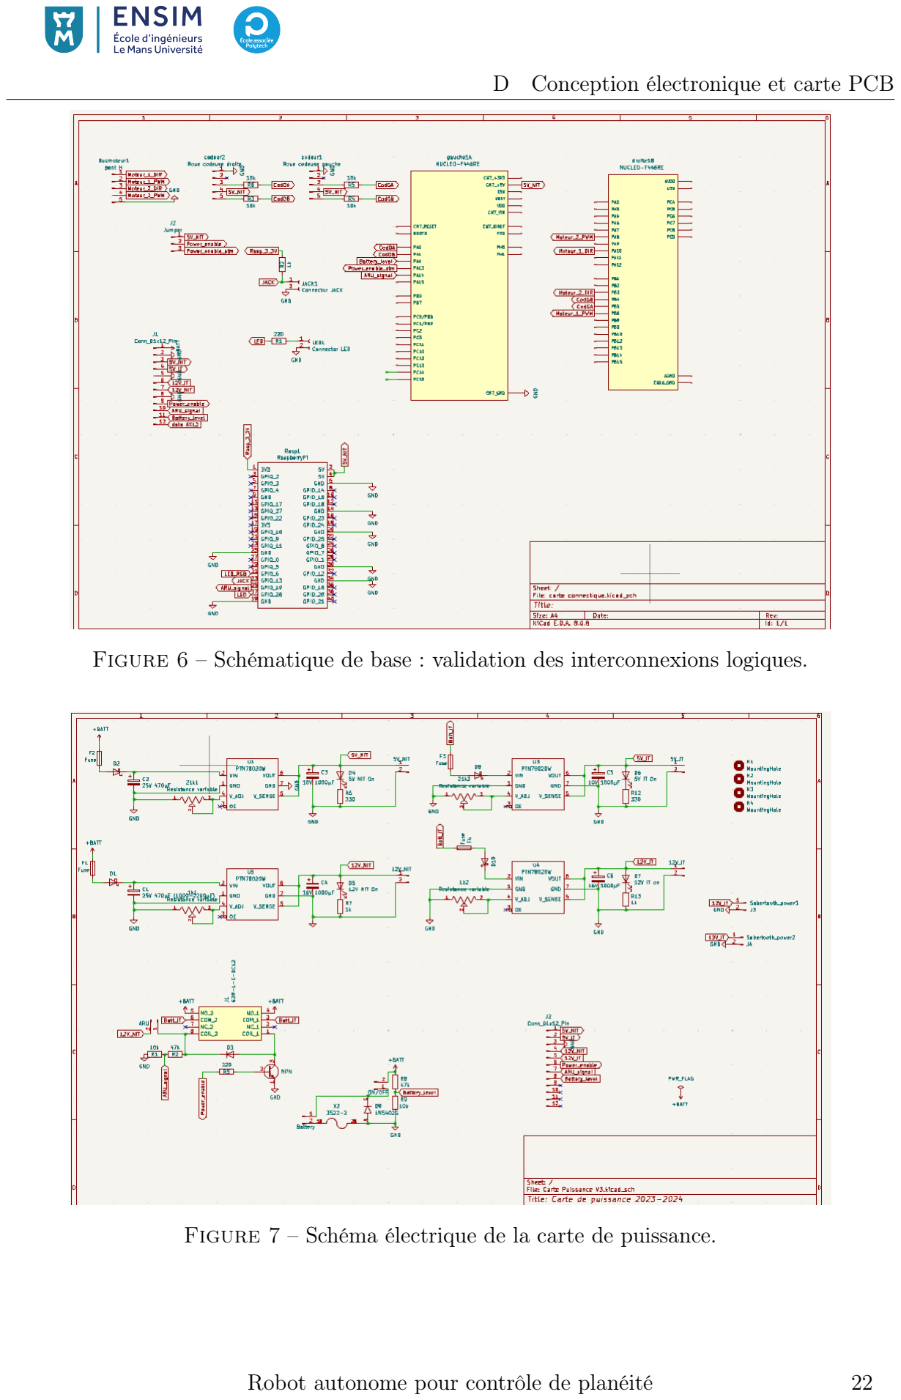
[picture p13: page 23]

D Conception électronique et carte PCB

Figure 6 – Schématique de base : validation des interconnexions logiques.

Figure 7 – Schéma électrique de la carte de puissance.

D Conception électronique et carte PCB

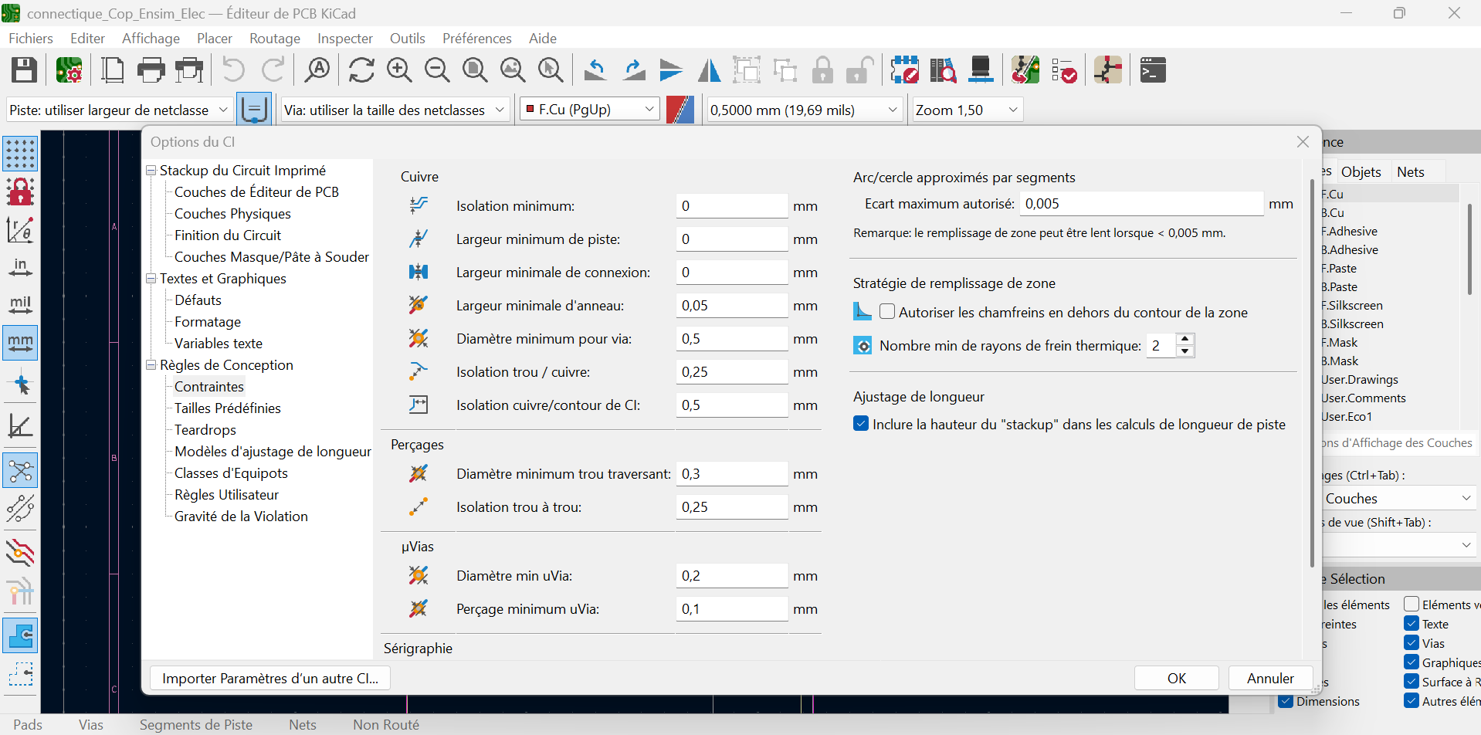
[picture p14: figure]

Figure 8 – Configuration des règles de conception (DRC) sous KiCad.

D.2 Réalisation de la carte

Cette section présente la réalisation concrète des cartes électroniques, au travers de vues 3D issues de l’outil de conception. Ces représentations permettent de visualiser l’implantation des composants et l’organisation générale des cartes.

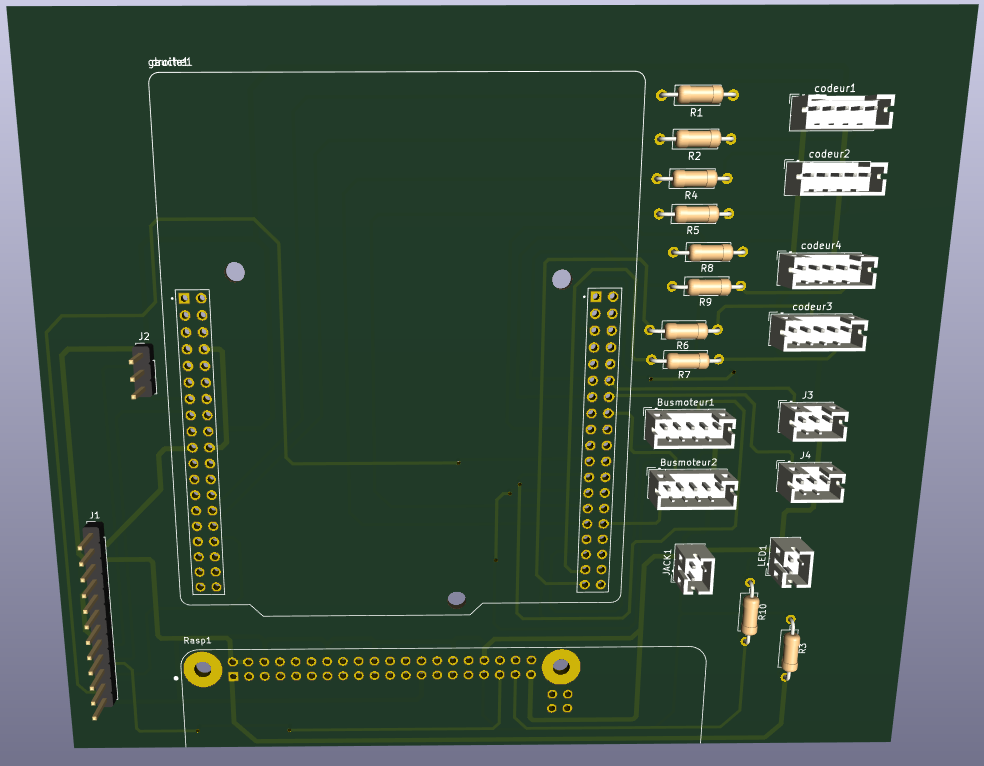
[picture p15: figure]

Figure 9 – Vue 3D de la carte de commande.

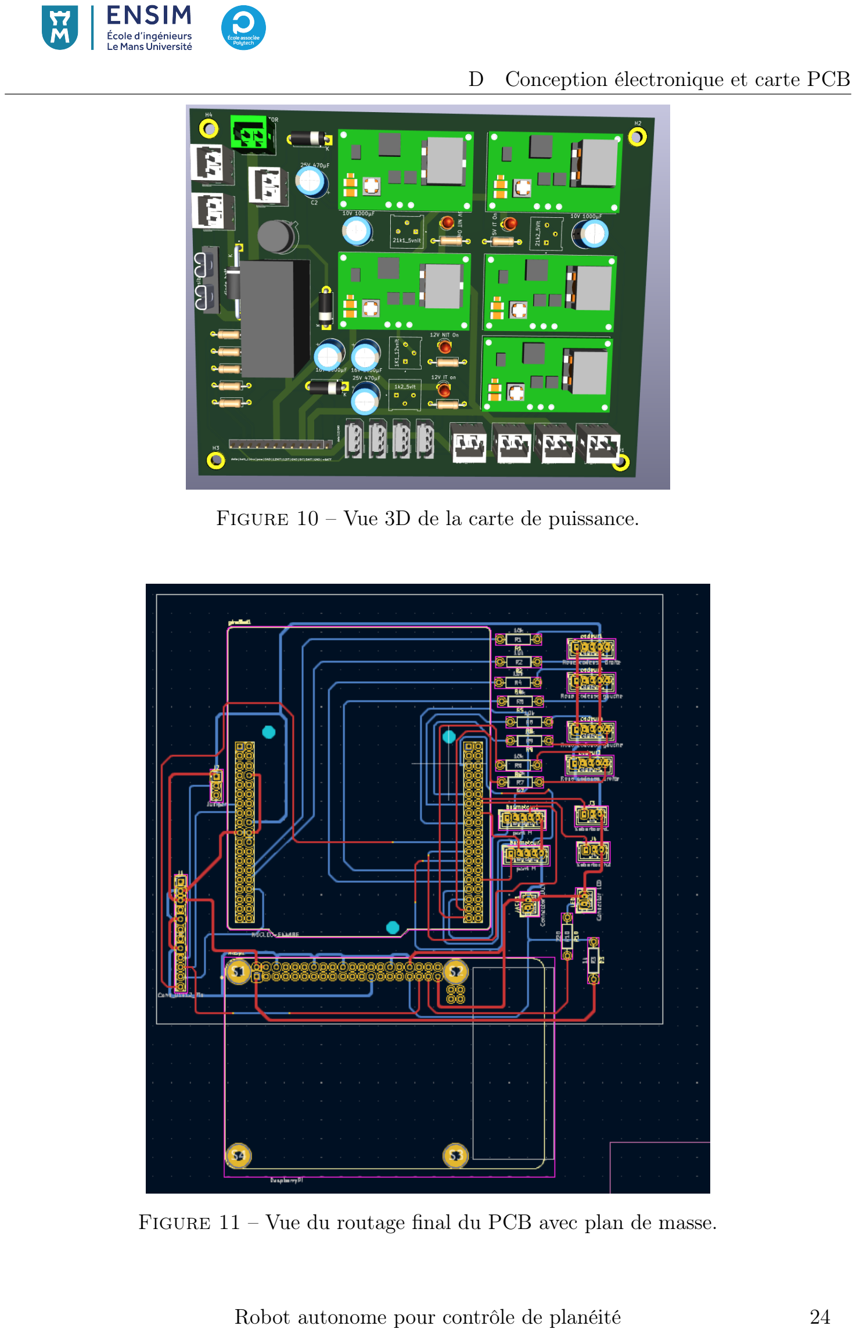
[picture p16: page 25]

D Conception électronique et carte PCB

Figure 10 – Vue 3D de la carte de puissance.

Figure 11 – Vue du routage final du PCB avec plan de masse.

F Communication des modules XBee

## E Déplacement du robot

E.1 Schéma de câblage moteur

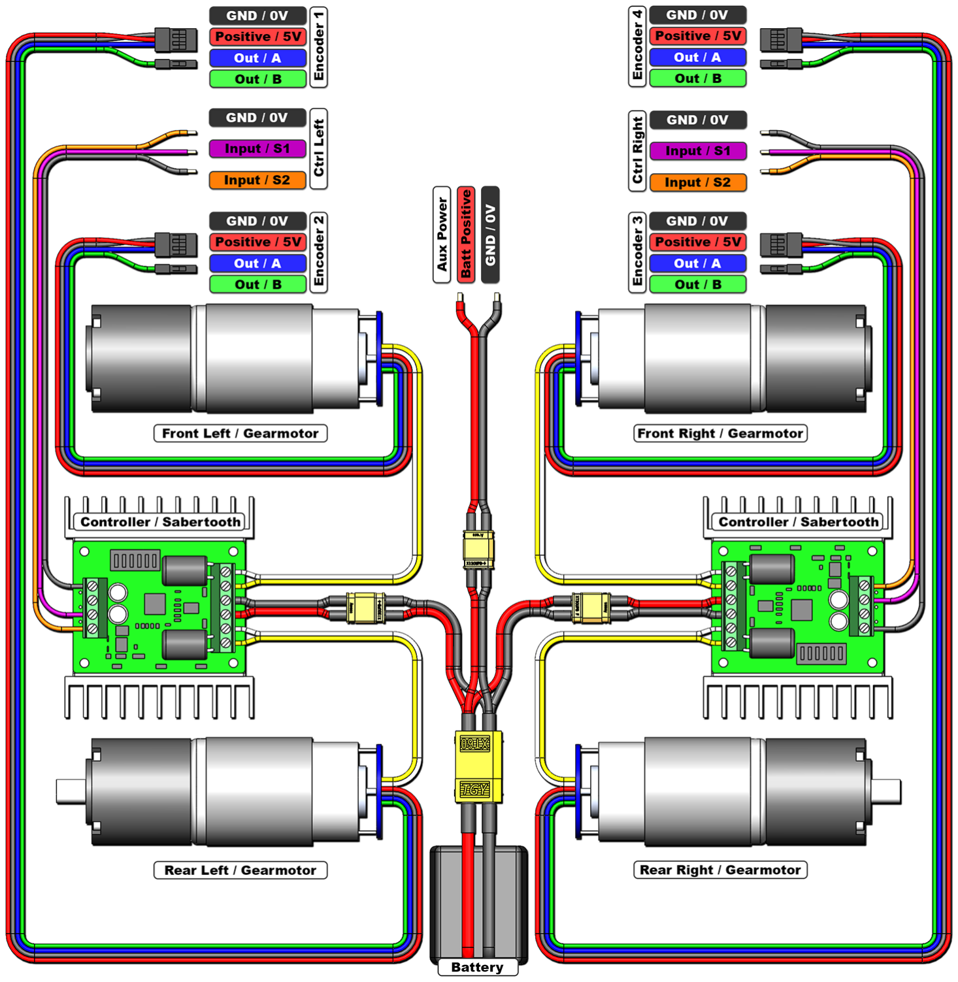
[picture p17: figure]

Figure 12 – Schéma officiel du câblage Sabertooth – quatre moteurs.

## F Communication des modules XBee

F.1 Configuration des modules

Captures d’écran de la configuration XCTU en mode AT.

F Communication des modules XBee

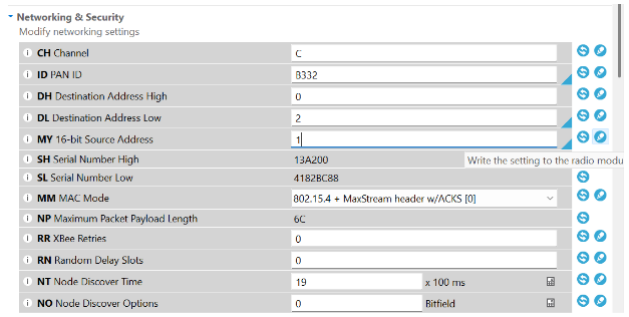
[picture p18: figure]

Figure 13 – Interface de configuration XCTU (Mode AT)

F.2 Tests de communication

Illustrations des échanges PC–Raspberry Pi et des tests de portée.

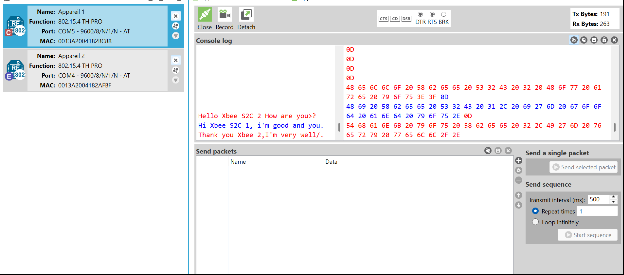
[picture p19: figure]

Figure 14 – Test de communication PC à PC via console XCTU

G Interface logicielle

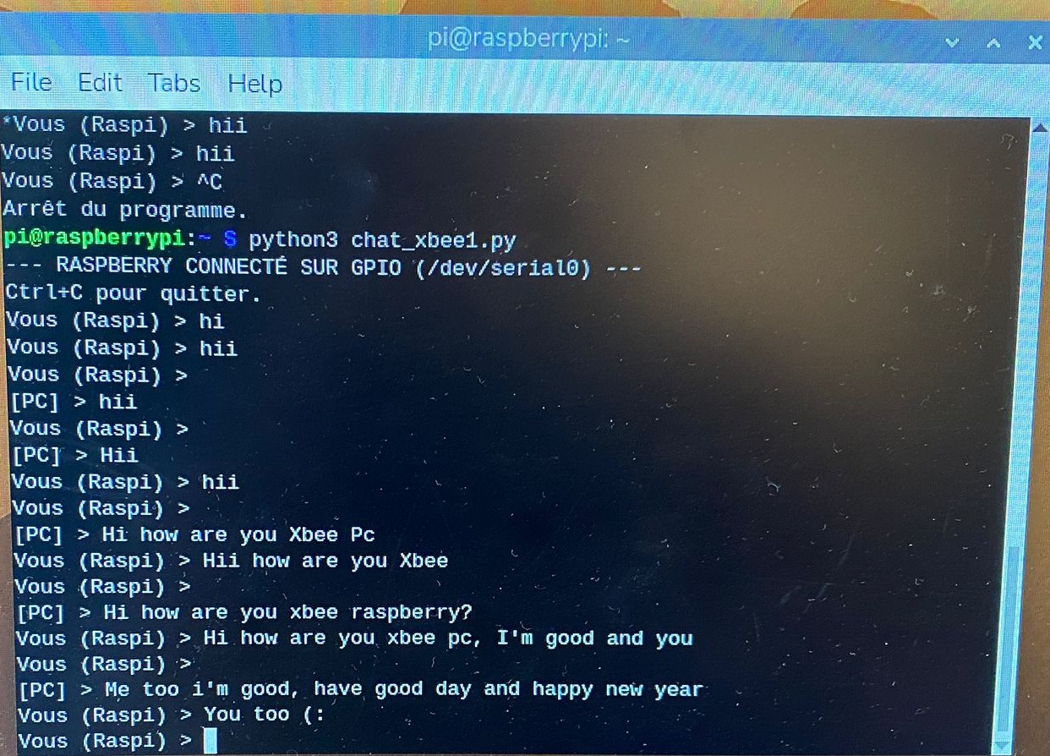
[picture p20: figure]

Figure 15 – Validation finale : Terminal côté Raspberry Pi

## G Interface logicielle

Captures d’écran de l’interface de commande et de supervision du robot.

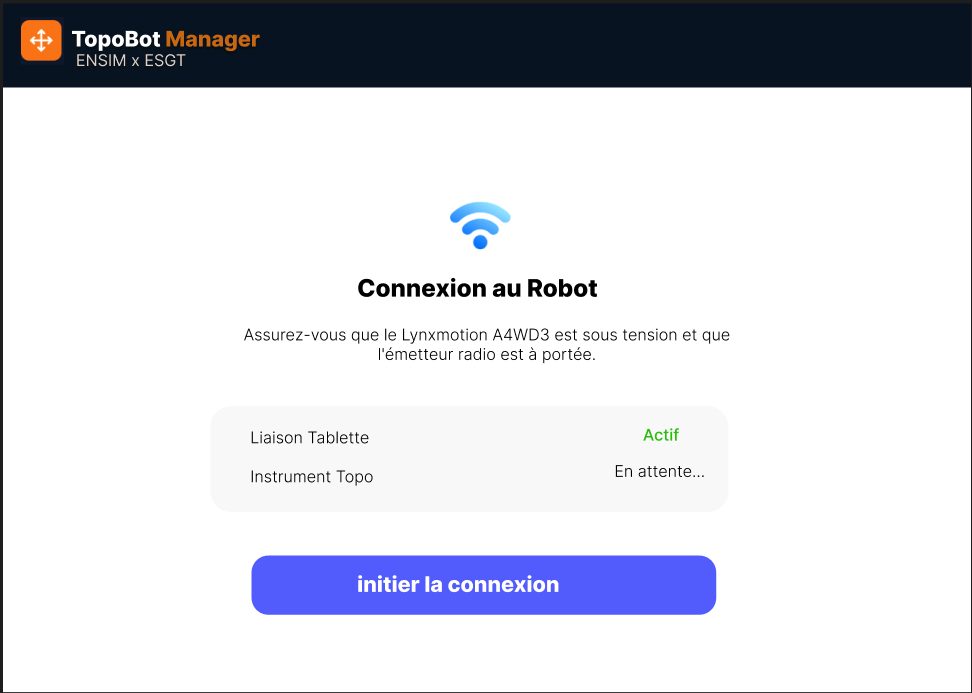
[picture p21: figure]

Figure 16 – Écran d’initialisation de la connexion sans fil.

G Interface logicielle

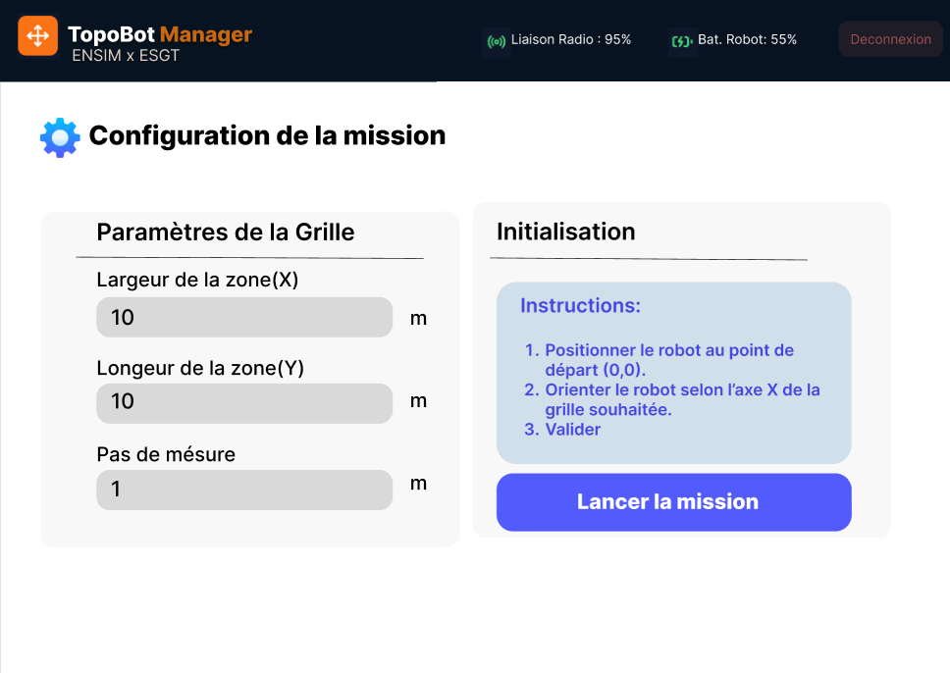
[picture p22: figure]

Figure 17 – Paramétrage de la grille de mesure et instructions de mise en station.

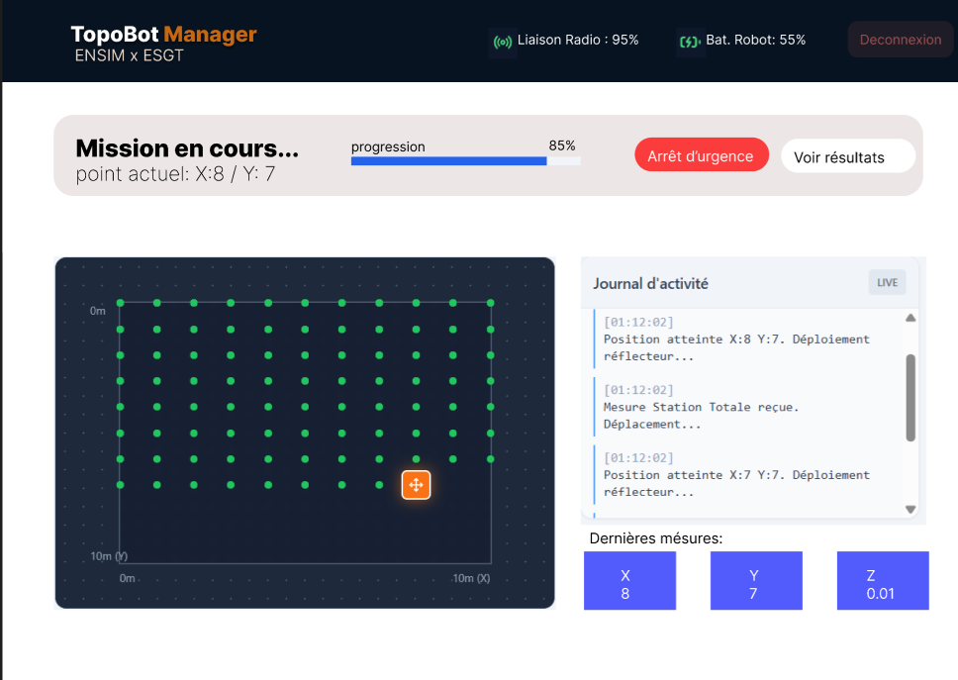
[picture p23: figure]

Figure 18 – Interface de supervision avec visualisation de la grille et logs en direct.

I Ressources complémentaires

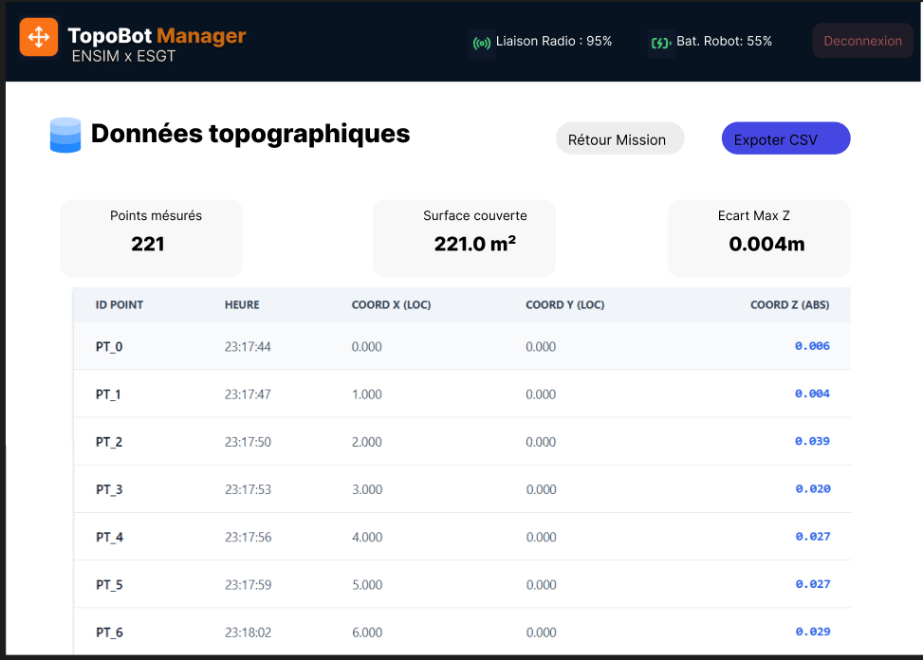
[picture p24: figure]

Figure 19 – Tableau récapitulatif des points mesurés et fonctionnalités d’export.

## H Codes sources

Cette annexe regroupe les principaux scripts Python développés dans le cadre du projet. Les extraits sont fournis à titre de référence.

H.1 Commande du déplacement

## I Ressources complémentaires

I.1 Liens utiles

— Tutoriel XBee : https://spin.atomicobject.com/xbee-tutorial/
— Logiciel Digi XCTU : https://www.digi.com/products/embedded-systems/digi-xctu — Documentation PySerial : https://pyserial.readthedocs.io/en/latest/

I.2 Vidéos de démonstration

— Diagnostic et correction du déplacement : https://drive.google.com/file/d/
| 1m8vA48erLxMlFajXNbC73RreMF-alR-H/view?usp=sharing (https://drive.google.com/file/d/1m8vA48erLxMlFajXNbC73RreMF-alR-H/view?usp=sharing)
— Validation communication XBee :

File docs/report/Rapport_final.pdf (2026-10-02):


# Développement d’un robot autonome guidé par station totale topographique pour le contrôle de planéité de surface

Projet 4A


Benewinde Kontiebo, Michael ESSOMBA, Arsène NGUENANG

YOUKAP, Aymane Fariss

Année universitaire : 2025-2026

Tuteur(s) université :

Matthieu Milharo
matthieu.milharo@univ-lemans.fr

## Résumé

Mots-clés : robot holonome, roues Mécanum, station totale, planéité, STM32, Raspberry Pi, Sabertooth, topographie. Ce rapport présente les travaux menés dans le cadre du projet de quatrième année à l’ENSIM, visant à développer un robot autonome capable d’automatiser le contrôle de planéité de surfaces à l’aide d’une station totale topographique. Le système s’appuie sur un châssis holonome Lynxmotion A4WD3 équipé de roues Mécanum, hérité d’une promotion précédente, et sur une architecture électronique entièrement repensée articulant une Raspberry Pi pour la supervision de haut niveau, un microcontrôleur STM32 F446RE pour le contrôle temps réel et deux cartes Sabertooth pour la commande de puissance des moteurs. Une carte de commande sur mesure a été conçue sous KiCad et fabriquée chez JLCPCB, intégrant la gestion des encodeurs, du servomoteur AX-12 dédié au déploiement du prisme, de l’arrêt d’urgence et du monitoring batterie. La logique de mission repose sur un balayage boustrophédon d’une grille paramétrable, piloté par un protocole binaire entre la Raspberry Pi et la STM32, avec une odométrie embarquée et une machine d’états garantissant la synchronisation des déplacements et des mesures. La communication avec la station totale est assurée par une liaison radio XBee, et l’ensemble est supervisé via une application tablette intuitive, TopoBot Manager, permettant la configuration, le suivi en temps réel et l’export des données au format CSV. Les essais ont validé les mouvements de base, l’architecture de commande et l’intégration du prisme, tout en mettant en évidence des axes d’amélioration majeurs : le réglage fin de l’asservissement, la fusion de données odométrie–station totale pour corriger les dérives, et le renforcement de la fiabilité de la liaison radio. Le projet a été réalisé pour un coût de 318,26 sur un budget de 500 , avec une démarche de réemploi systématique du matériel existant.

## Abstract

Keywords : holonomic robot, Mecanum wheels, total station, flatness control, STM32, Raspberry Pi, Sabertooth, surveying. This report presents the work carried out as part of a fourth-year engineering project at ENSIM, aiming to develop an autonomous robot for automated surface flatness inspection using a robotic total station. The system is built upon a Lynxmotion A4WD3 holonomic chassis fitted with Mecanum wheels, inherited from a previous cohort, and relies on a redesigned electronic architecture combining a Raspberry Pi for high-level supervision, an STM32 F446RE microcontroller for real-time control, and two Sabertooth motor drivers. A custom control board was designed in KiCad and manufactured by JLCPCB, integrating encoder management, an AX-12 servo for prism deployment, an emergency stop circuit, and battery monitoring. The mission logic implements a boustrophedon sweep over a configurable grid, driven by a lightweight binary protocol between the Raspberry Pi and the STM32, with onboard odometry and a state machine ensuring proper synchronisation between motion and measurement sequences. Communication with the total station is handled through an

Robot autonome pour contrôle de planéité | 1

XBee radio link, and the entire system is supervised via an intuitive tablet application, TopoBot Manager, which provides mission configuration, real-time monitoring, and CSV data export. Testing validated the basic motion capabilities, the command architecture, and the prism integration, while highlighting key areas for improvement : fine-tuning the control loop, implementing odometry–total station data fusion to compensate for drift, and enhancing radio link reliability. The project was completed at a cost of 318.26 out of a 500 budget, with systematic reuse of existing hardware components.

Table des matières

## Table des matières

Résumé | 1
Abstract | 1
1 Introduction | 5
2 État de l’art et Architecture | 5
3 Analyse fonctionnelle et définition des objectifs | 6
4 Conception et intégration électronique | 8
5 Commande du déplacement et logique de mission autonome | 10
6 Communication et interfaçage avec la station totale | 16
7 Supervision et contrôle : l’application TopoBot Manager | 18
8 Rétrospective globale et perspectives d’amélioration | 21
9 Bilan financier du projet | 22

Table des matières

10 Étude d’impact environnemental | 23
11 Conclusion | 25
Déclaration d’utilisation d’outils d’intelligence artificielle | 26
A Annexes | 27
B Cahier des charges détaillé | 27
C Assemblage et câblage final du robot | 29

2 État de l’art et Architecture

## 1 Introduction

L’histoire de ce projet naît d’une synergie singulière : la proximité immédiate de deux écoles aux expertises complémentaires sur le campus du Mans. D’un côté, l’ENSIM, forte de son savoir-faire en robotique et en systèmes embarqués ; de l’autre, l’ESGT, avec sa maîtrise pointue de la topographie. C’est précisément à la croisée de ces deux disciplines que s’inscrit notre mission : donner vie à un prototype robotique capable d’automatiser entièrement le contrôle de planéité d’une surface.Pour relever ce défi, notre point de départ s’appuie sur des choix techniques éprouvés. Nous devons transformer notre plateforme matérielle ;un châssis holonome Lynxmotion A4WD3 équipé de roues mécanum et animé par deux cartes Sabertooth,en un véritable explorateur autonome.Grâce à une liaison radio robuste par un module Xbee, le robot aura pour mission de déposer au sol un réflecteur sphérique de 40 mm de diamètre. Il devra ensuite l’orienter avec précision vers la station totale et lui ordonner d’enregistrer ses coordonnées 3D, avant de stocker lui-même cette précieuse information.Cette minutieuse chorégraphie devra se répéter inlassablement. Le système est pensé pour exécuter un balayage automatique, positionnant le réflecteur point par point sur une grille virtuelle dont l’origine et l’orientation seront définies dès le premier placement. Avec une cible d’autonomie particulièrement exigeante, couvrir une surface de 50 mètres par 50 avec un pas d’un demi-mètre, le tout sur une seule charge, le défi énergétique et algorithmique est colossal.Enfin, parce qu’une prouesse technique ne prend tout son sens que si elle est maîtrisable, l’ensemble de ces opérations complexes sera masqué derrière une interface d’utilisation intuitive. Accessible à tout public depuis une tablette ou un smartphone, cette interface de configuration permettra de piloter le robot du bout des doigts, transformant une tâche topographique fastidieuse en un processus fluide, intelligent et entièrement automatisé.

## 2 État de l’art et Architecture

### 2.1 État de l’existant et prise en main du matériel

Au lancement de ce projet, notre première étape a consisté à dresser l’état des lieux de l’existant. Loin de partir d’une page blanche, nous avons pu nous appuyer sur les fondations matérielles posées par nos prédécesseurs. Si le robot n’était pas encore en capacité de se mouvoir, nous disposions néanmoins d’une base solide : le châssis, le prisme topographique, un module de communication XBee, ainsi que les contrôleurs de puissance Sabertooth. À cela s’ajoutait une modélisation 3D préliminaire du support du prisme, intégrant un système de pignon-crémaillère. Ce mécanisme, pensé pour être actionné par un servomoteur AX-12, doit permettre d’automatiser la délicate cinématique de dépose et de relevage du prisme au sol. Notre tout premier défi a donc été de nous approprier cet héritage technique, de le fiabiliser et de l’animer pour transformer cet assemblage initial en un système pleinement opérationnel.

3 Analyse fonctionnelle et définition des objectifs

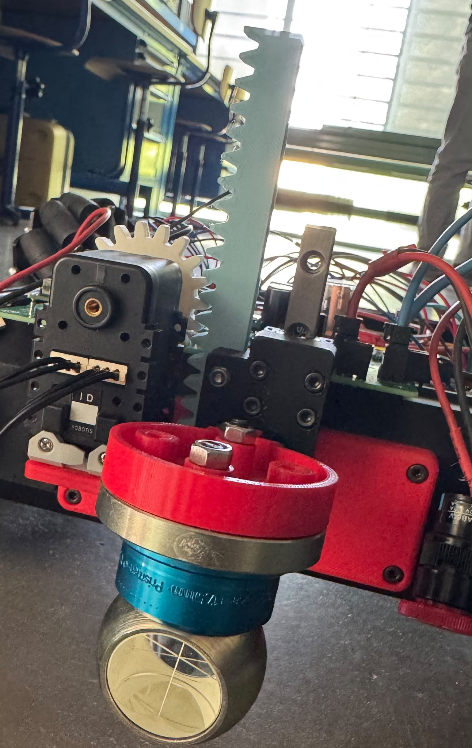
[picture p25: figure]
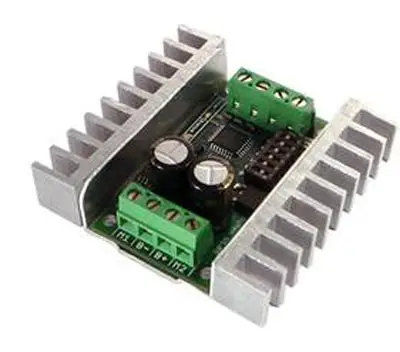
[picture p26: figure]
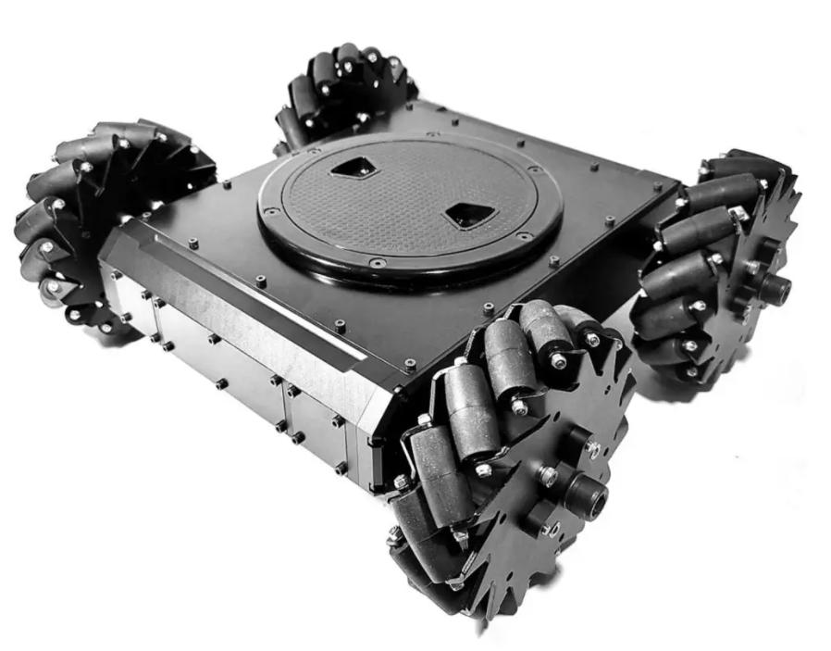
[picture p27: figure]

Figure 2 – Châssis Lynxmotion, module Sabertooth et mécanisme prisme-crémaillère

## 3 Analyse fonctionnelle et définition des objectifs

Une fois l’inventaire matériel dressé et notre base technique sécurisée, la seconde étape de notre démarche a consisté à traduire les ambitions du projet en véritables fonctions opératoires. Pour que ce système passe du statut de simple plateforme motorisée à celui d’assistant topographique autonome, nous devions définir avec précision l’ensemble des comportements attendus.
Afin de répondre aux exigences de la mission, le robot devait être capable de maîtriser quatre grands domaines d’action :

— La mobilité et la navigation intelligente : Le système doit pouvoir se déplacer de manière autonome et sécurisée, aussi bien en environnement clos (couloirs) qu’en zone non préparée. Cela implique la détection et l’évitement des obstacles et des vides. Surtout, la navigation doit être d’une grande précision pour exécuter le balayage systématique d’une grille de 50 × 50 mètres avec un pas rigoureux de 0, 5 mètre. — La cinématique et l’interaction physique : Le robot doit gérer la mécanique de précision liée au réflecteur topographique. Il est impératif d’asservir le servomoteur AX-12 pour piloter le système de pignon-crémaillère, assurant ainsi une dépose et un relevage fluides du prisme de 40 mm, tout en garantissant son orientation parfaite vers la station totale.
— La communication et le traitement des données : Le système embarqué doit orchestrer un dialogue constant et bidirectionnel avec l’instrument topographique via la liaison radio. Il lui incombe de déclencher la prise de mesure au moment opportun, puis de récupérer, traiter et stocker les coordonnées 3D générées.
— La supervision et l’accessibilité : L’ensemble de la mission doit pouvoir être configuré et paramétré (origine, orientation des axes de la grille, pas de mesure) par un opérateur sans expertise robotique, au travers d’une interface homme-machine (IHM) intuitive, accessible depuis un support mobile (smartphone ou tablette).

3 Analyse fonctionnelle et définition des objectifs

### 3.1 Vers la structuration des tâches

C’est précisément cette cartographie des compétences requises qui a dicté l’organisation de notre travail. En décomposant le comportement global du robot en un ensemble d’actions indépendantes mais interconnectées, nous avons pu identifier les différents verrous technologiques à lever. Cette démarche analytique nous a naturellement conduits à répartir le projet en grands pôles de développement et à établir une planification structurée de nos tâches.
— Supervision et Interface Utilisateur (Bénéwindé Kontiebo, Chef de projet) : Gestion globale du projet, développement de l’interface de contrôle et structuration de l’expérience utilisateur (IHM) pour garantir une prise en main fluide et intuitive.
— Communication et Transmission (Aymane Fariss) : Mise en place de la communication XBee, configuration de la liaison radio entre le robot et la station topographique, et réalisation des tests de robustesse du signal.
— Électronique et Intégration (Arsène Nguenang Youkap) : Conception des cartes électroniques (PCB), réalisation du câblage de puissance et de commande, et intégration matérielle complète des composants sur le châssis.
— Asservissement et Cinématique (Michael Essomba) : Programmation des algorithmes de contrôle, avec une attention particulière portée au pilotage et à l’asservissement du servomoteur AX-12 pour le mécanisme de relevage du prisme.

### 3.2 Méthodologie de gestion de projet et suivi des tâches

Pour assurer une progression constante et une réactivité optimale face aux différents verrous techniques, la gestion de ce projet a été menée selon une démarche agile inspirée du framework Scrum. L’organisation, la répartition et le suivi opérationnel des tâches ont été centralisés sur une plateforme collaborative interne mise à disposition par l’université. Ce pilotage s’est articulé autour d’un rythme hebdomadaire rigoureux. Chaque jeudi, en amont des sessions de travail matériel et logiciel, l’équipe se réunissait pour une séance de synchronisation. Cette réunion technique permettait d’évaluer l’état d’avancement de chacun, de valider les fonctionnalités développées lors du cycle précédent et de planifier les objectifs prioritaires de la semaine à venir.
En complément de cette dynamique interne, un dispositif de restitution transparent a été instauré avec notre enseignant encadrant. À chaque étape clé, un point de situation formalisé lui était transmis via la plateforme universitaire. Ce compte-rendu structuré permettait de faire un état des lieux précis.
“‘latex

4 Conception et intégration électronique

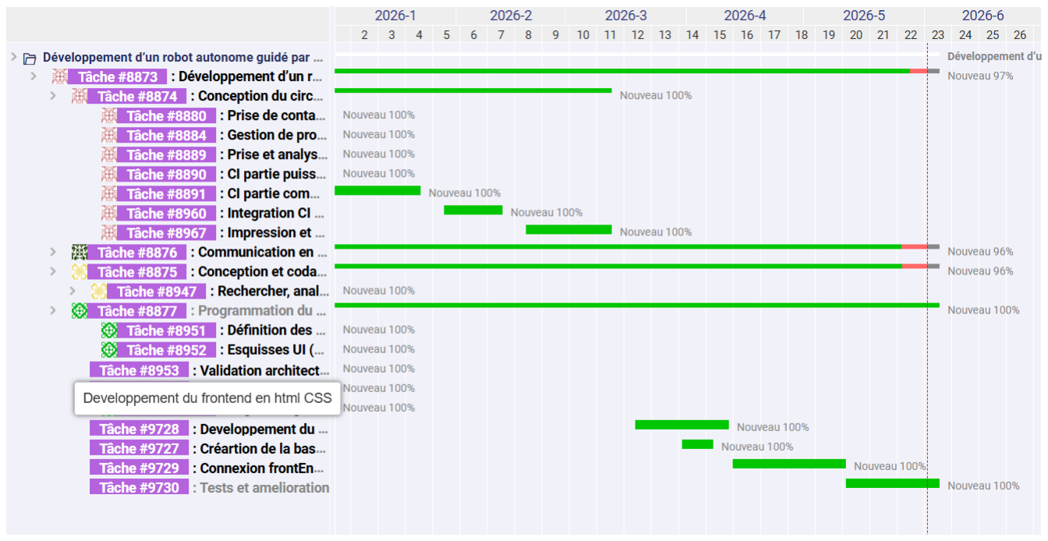
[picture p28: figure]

Figure 3 – Diagramme de Gantt du projet : planification macroscopique des tâches et jalons clés.

## 4 Conception et intégration électronique

Pour aborder la conception électronique du système, notre première démarche a consisté à analyser des architectures existantes afin d’en tirer les meilleures pratiques. Nous nous sommes notamment inspirés du robot développé par l’association ENSIMElec. L’étude de sa logique de fonctionnement nous a conduits à structurer notre propre électronique autour de deux entités distinctes : une carte de puissance et une carte de commande. La carte de puissance existante répondait déjà à nos exigences énergétiques pour la motorisation. Nous avons donc fait le choix de la conserver en l’état, sans modification matérielle, afin d’alimenter les actionneurs de manière fiable et sécurisée.
En revanche, la carte de commande a nécessité une conception sur mesure pour s’adapter à la cinématique de notre base holonome et aux besoins de contrôle embarqué du robot. À l’aide du logiciel KiCad, nous avons réalisé la schématique et le routage de notre propre circuit imprimé, ou PCB. Cette nouvelle carte centralise les connexions entre les différents sous-systèmes et s’articule autour d’un microcontrôleur STM32 associé à une Raspberry Pi. Elle intègre plusieurs interfaces de contrôle et d’acquisition :

— la gestion de quatre encodeurs rotatifs, indispensables à l’asservissement des moteurs et à l’amélioration de la précision des déplacements de la base holonome ; — une interface dédiée au servomoteur AX-12, utilisée pour le déploiement et le relevage du prisme topographique ;
— un circuit d’arrêt d’urgence manuel, permettant d’interrompre rapidement la motorisation afin de limiter les risques matériels ;
— un système centralisé de gestion de l’alimentation, incluant l’allumage et l’extinction des différents sous-ensembles ;
— des ports de communication prévus pour des capteurs à ultrasons, en vue d’un

4 Conception et intégration électronique

futur évitement d’obstacles ;
— un convertisseur analogique-numérique, utilisé pour le suivi de l’état de la batterie.
Cette architecture électronique permet ainsi de séparer clairement la puissance, le contrôle temps réel et la supervision logicielle. Elle constitue une base plus robuste pour la suite du projet, notamment pour l’asservissement, la gestion de mission et l’intégration des organes liés à la mesure topographique. “‘

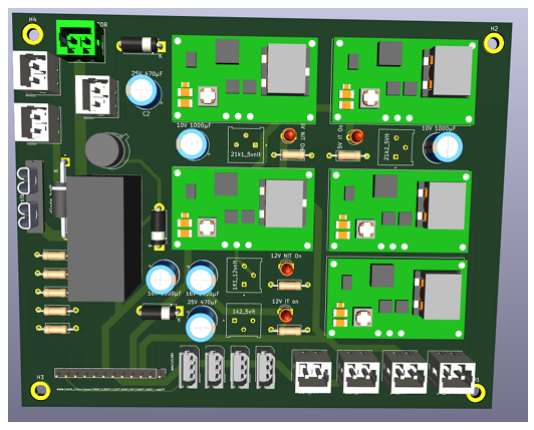
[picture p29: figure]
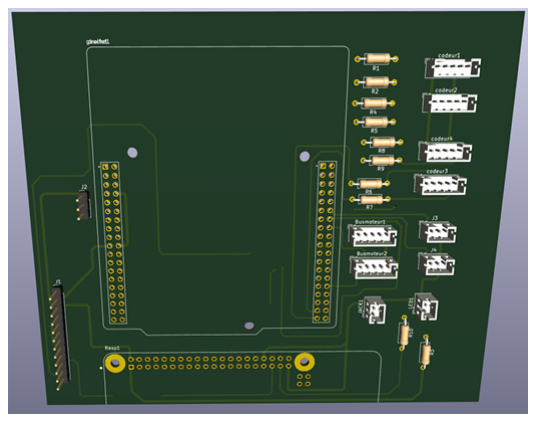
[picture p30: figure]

Figure 4 – Vues 3D des cartes de commande et de puissance finalisées.

Une fois la phase de conception logicielle achevée et le routage validé, nous avons exporté les fichiers Gerber pour commander la fabrication du PCB auprès du fournisseur JLCPCB. À réception des circuits imprimés, nous avons procédé à l’assemblage et au soudage minutieux de l’ensemble des composants. Cette ultime étape nous a permis d’obtenir des cartes fonctionnelles, fiables et prêtes à être intégrées au sein du châssis robotique.

5 Commande du déplacement et logique de mission autonome

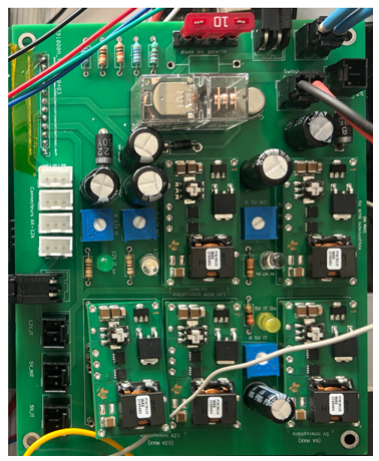
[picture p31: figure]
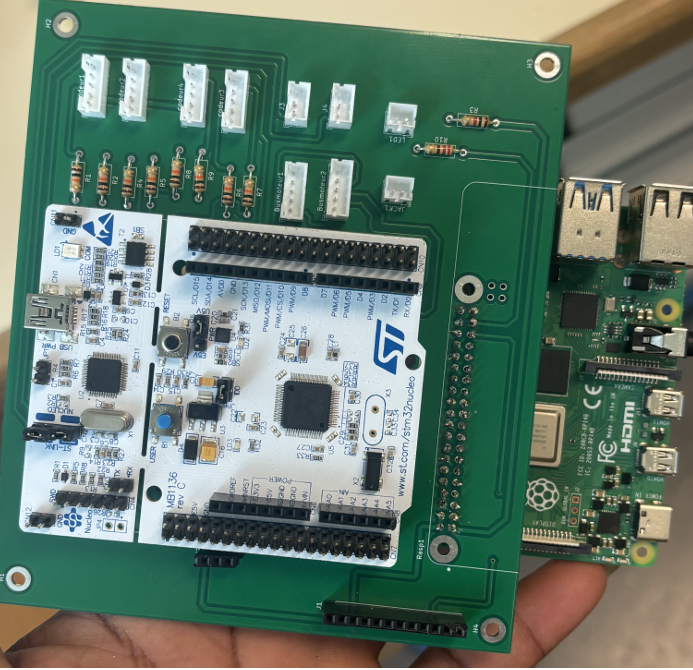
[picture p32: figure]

Figure 5 – Cartes de commande et de puissance finalisées après assemblage et soudure des composants.

## 5 Commande du déplacement et logique de mission autonome

Cette partie présente les travaux réalisés sur la commande du déplacement du robot. L’évolution principale de cette année réside dans le passage d’une commande par mouvements élémentaires à une architecture capable de recevoir des objectifs de position et d’exécuter une mission structurée point par point. La démarche a été progressive : simulation des mouvements de la base Mécanum, validation sur prototype réel, intégration de l’odométrie et de la logique de mission, puis intégration du servomoteur AX12 et du prisme pour rapprocher le prototype de son usage topographique final.

### 5.1 Principe de déplacement de la base Mécanum

La base Mécanum permet théoriquement les translations et la rotation sur place. Dans la mission actuelle, le déplacement est principalement exploité en translation sur une grille, avec une orientation maintenue constante. Le paramètre θ est conservé dans le protocole MOVE_TO(x,y,θ) afin de garder une architecture évolutive et compatible avec une commande complète de pose.

5 Commande du déplacement et logique de mission autonome

Table 1 – Combinaisons de rotation des roues pour les mouvements élémentaires

Mouvement | AV G | AV D | AR G | AR D
Translation avant | + | + | + | +
Translation arrière | - | - | - | -
Latéral gauche | - | + | + | -
Latéral droit | + | - | - | +
Rotation gauche | - | + | - | +
Rotation droite | + | - | + | -

### 5.2 Simulation et préparation des mouvements

Avant les essais physiques, une phase de simulation a été réalisée à partir du modèle SolidWorks du robot. Les vues issues de SolidWorks Composer ont permis de vérifier la disposition des roues, l’encombrement du châssis et la cohérence de la plateforme.


Figure 6 – Simulation du déplacement longitudinal latéral .

La simulation a également permis de préparer la logique de mission : parcours boustrophédon ligne par ligne pour couvrir une zone rectangulaire avec un pas configurable.
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

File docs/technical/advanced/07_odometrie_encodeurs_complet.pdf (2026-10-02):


TopoBot - Documentation de passation - Juin 2026 | Page 1

# 07 - Odometrie et encodeurs

### Documentation completee avec schemas, procedures et tableaux de validation

Version | 1.1 - version completee avec schemas
Date | Juin 2026
Projet | TopoBot - ENSIM x ESGT
Usage | Passation technique pour la prochaine promotion

## Sommaire

1. Role de l odometrie
2. Encodeurs et timers
3. Chaine de calcul
4. Tests roue par roue
5. Calibration
6. Limites et fusion Topcon
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

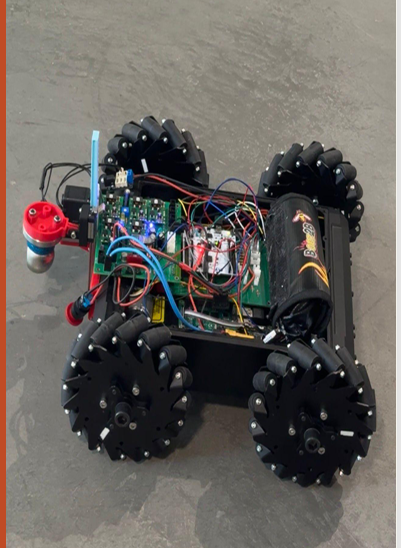
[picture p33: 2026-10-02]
assets/images/hero/robot-overview.png

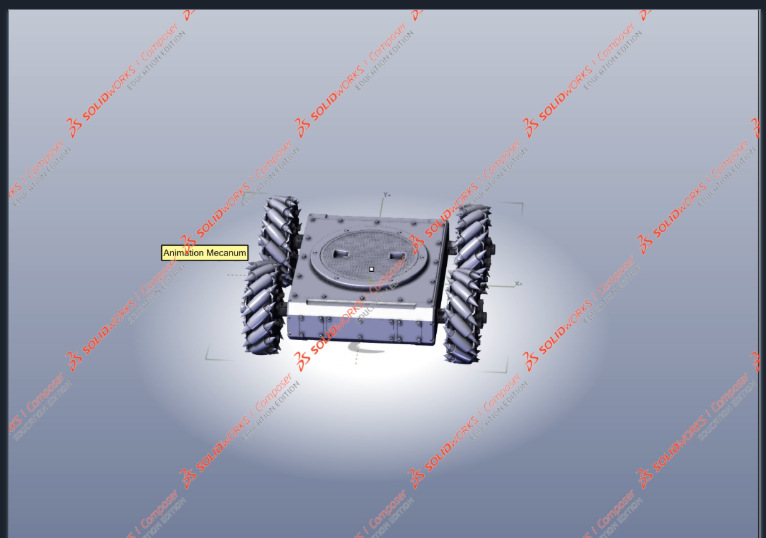
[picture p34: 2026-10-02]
assets/images/hardware/robot-cad-render.png

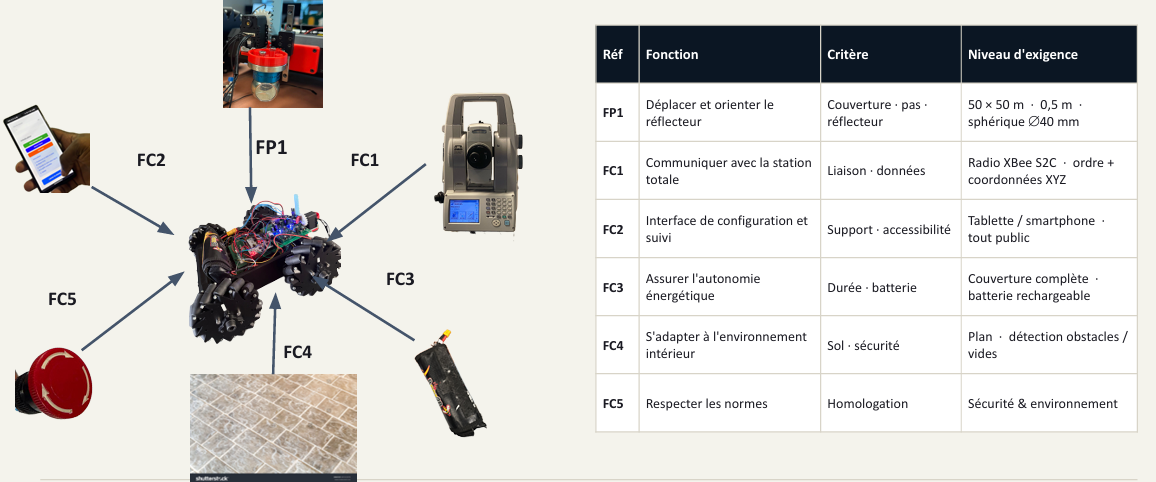
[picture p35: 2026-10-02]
assets/images/diagrams/system-architecture.png

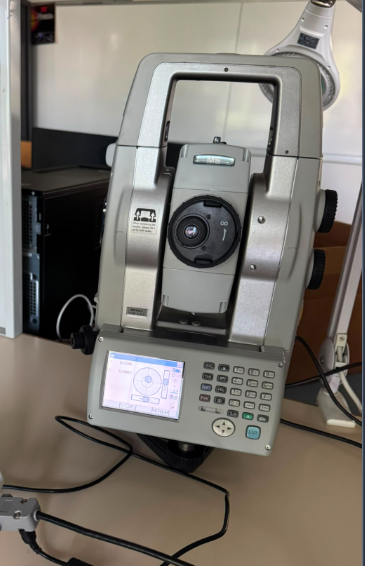
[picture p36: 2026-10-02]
assets/images/hardware/total-station.png

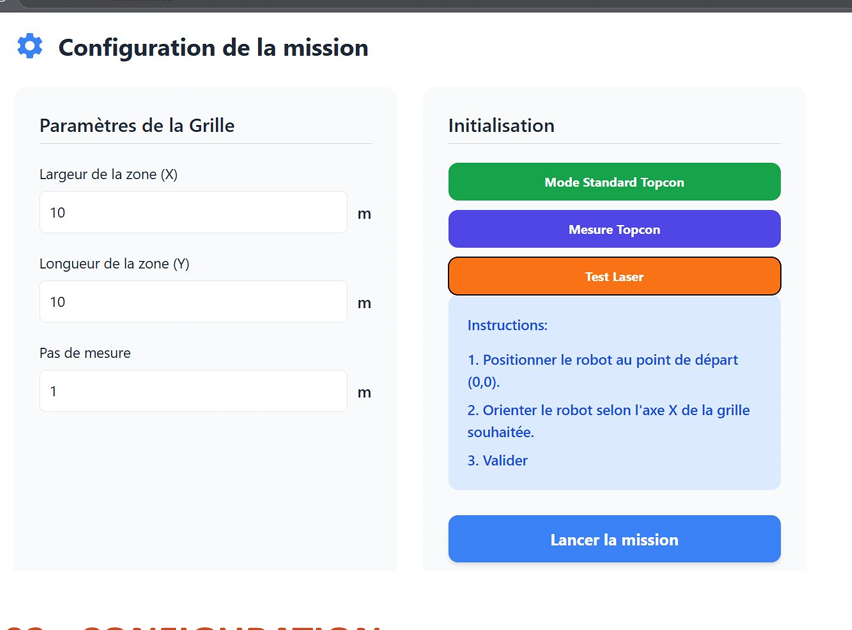
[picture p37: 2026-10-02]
assets/images/topobot-manager-dashboard.png

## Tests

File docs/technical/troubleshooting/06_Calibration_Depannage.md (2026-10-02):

# 6 — Calibration & dépannage

## Partie A — Calibration

Tous les paramètres se règlent dans **`Core/Inc/robot_config.h`**. Après
modification : recompiler et reflasher le STM32.

### A.1 Dimensions du robot

À **mesurer physiquement** et reporter :

| Constante | Signification | Valeur actuelle |
|---|---|---|
| `WHEEL_RADIUS_M` | rayon d'une roue (m) | `0.076` (à vérifier !) |
| `WHEEL_BASE_LX` | demi‑empattement avant/arrière (m) | `0.110` |
| `WHEEL_BASE_LY` | demi‑empattement gauche/droite (m) | `0.18725` |

> `WHEEL_RADIUS_M` porte la mention « à vérifier ». Mesurez le **diamètre** réel
> d'une roue (galets inclus) et divisez par 2.

### A.2 Encodeurs

| Constante | Rôle |
|---|---|
| `ENCODER_PPR` | lignes physiques de l'encodeur (`12`) |
| `ENCODER_COUNTS` | = PPR × 4 (quadrature ×4) |
| `GEAR_RATIO` | rapport de réduction de la boîte (`51.0`) |
| `ENC_POL_*` | polarité de comptage (+1 / −1) par roue |

### A.3 Calibration de la distance (`TICKS_PER_METER`)

C'est **la** calibration la plus importante pour la précision des
déplacements.

Procédure :
1. Reset odométrie (`CMD_RESET_ODOM`).
2. Poussez le robot **bien droit sur 1,00 m** mesuré au mètre (ou commandez un
   déplacement et mesurez le réel).
3. Lisez la valeur `x` affichée par l'odométrie (`test_encoders.py` ou
   `test_odom.py`).
4. Ajustez le multiplicateur `TICKS_PER_METER_CALIB` :
   - si l'odométrie affiche **moins** que la distance réelle → **réduisez** ;
   - si elle affiche **plus** → **augmentez**.

> Actuellement `TICKS_PER_METER_CALIB = 1.0` (remis à 1.0 après la correction du
> mapping encodeurs du 2026‑05‑22). L'ancienne valeur 4.64 compensait un mapping
> erroné. **À recalibrer proprement** une fois les 4 encodeurs réparés.

### A.4 Asservissement de position

| Constante | Rôle | Valeur |
|---|---|---|
| `PID_X_KP`, `PID_Y_KP` | gain proportionnel | `3.0` |
| `VELOCITY_CAP` | plafond de vitesse en sortie | `0.10` m/s |
| `VELOCITY_DEADBAND` | sous ce seuil, sortie forcée à 0 | `0.015` m/s |
| `ACCEL_MAX` | rampe d'accélération | `0.40` m/s² |
| `DIAG_VEL_THRESH` | seuil de correction séquentielle des axes | `0.050` m/s |
| `POS_TOLERANCE_M` | tolérance d'arrivée | `0.015` m |
| `SETTLE_CYCLES` | cycles stables avant de valider l'arrivée | `20` (= 200 ms) |

> `VELOCITY_CAP = 0.10 m/s` a été validé empiriquement : au‑dessus, certaines
> roues ne tournaient pas uniformément. Ne montez pas sans retester.

### A.5 Normalisation moteurs

| Constante | Rôle | Valeur |
|---|---|---|
| `MAX_VX`, `MAX_VY` | vitesse correspondant à 100 % Sabertooth | `0.40` m/s |
| `MIN_MOTOR_NORM` | zone morte moteur (sous ce % → 0) | `0.02` |

> Si certaines roues ne **démarrent pas** à basse consigne, remontez
> `MIN_MOTOR_NORM` à 0.03–0.04.

### A.6 Servo AX12 (positions du prisme)

| Constante | Rôle | Valeur |
|---|---|---|
| `AX12_ID_PRISM` | ID Dynamixel du servo | `2` |
| `AX12_POS_DEPLOY` | position déployée (0…1023) | `700` |
| `AX12_POS_RETRACT` | position rentrée | `200` |

> Ajustez les positions selon la course mécanique réelle du bras du prisme.

---

## Partie B — Dépannage

### Le robot ne bouge pas du tout
- Alimentation puissance : le relais **PA5** doit être actif (firmware le met à
  l'état haut au démarrage). Batterie chargée ?
- LED des Sabertooth : rouge = pas de signal valide. Vérifiez le câblage UART4
  (PC10) et les **adresses DIP** (128 / 129).
- Lancez `test_comm.py` pour isoler la chaîne logicielle.

### Une seule roue tourne / le robot part de travers
- Consigne sous le seuil de démarrage moteur → augmentez `MIN_MOTOR_NORM` ou
  travaillez au‑dessus de `VELOCITY_DEADBAND`.
- Vérifiez les polarités `POL_*` (`mecanum.c`) avec `test_motor_mapping.py`.

### Une roue tourne à l'envers
- Inversez le signe `POL_xx` correspondant dans `mecanum.c` (plutôt que les
  fils).

### L'odométrie est fausse / dérive
- **Cause n°1 (la plus fréquente)** : la **carte de commande** a un faux contact
  et une ou plusieurs roues **ne comptent plus**. Les 4 encodeurs sont bons,
  mais si la carte ne transmet pas les tics, l'odométrie est fausse.
  → **Avant chaque test**, lancez `test_encoders.py`, tournez les 4 roues à la
  main et confirmez que chacune incrémente. Repositionnez / vérifiez la carte
  tant que ce n'est pas le cas.
- Rappel firmware : `ODOM_REAR_ONLY=1` n'exploite que RL/RR et **force θ à 0**.
  Une fois les 4 roues confirmées fiables, vous pouvez repasser ce define à `0`.
- Vérifiez ensuite `TICKS_PER_METER` (voir A.3) et les polarités encodeurs.

### La réception STM32 se bloque (plus aucune réponse) ⚠️
- **Bug d'overrun UART connu** : pendant les ≈17 ms d'envoi aux Sabertooth, un
  octet reçu de la Pi peut être perdu et bloquer la réception (flag ORE non
  nettoyé).
- **Contournement immédiat** : appuyer sur le **reset** de la Nucleo.
- **Contournements logiciels** : ne pas envoyer de `GET_STATUS` pendant un
  mouvement (cf. `test_robotf4.py`), ou ajouter un `HAL_UART_ErrorCallback` qui
  nettoie l'erreur et relance la réception (cf. besoin de `test_robotf5.py`).
- Correctif de fond proposé dans la [passation](08_Passation/README.md).

### L'ARU se déclenche tout seul
- Parasites moteurs sur PB14. Le firmware filtre déjà (debounce 50 ms) ; si ça
  persiste, vérifiez le câblage / blindage, ou augmentez `ARU_DEBOUNCE_CYCLES`
  dans `robot_control.c`.

### La station Topcon ne mesure pas
- Vérifiez le port (`/dev/ttyUSB0`), le XBee, le débit (9600).
- Lancez `test_xbee.py` puis `python ms1ax.py /dev/ttyUSB0 mes`.
- La station doit **viser le prisme** ; en tracking elle peut le perdre si le
  robot va trop vite.
- Ne raccourcissez pas les `time.sleep` des séquences Topcon.

### Le frontend n'affiche rien / page blanche
- `frontend/dist` existe ? Sinon `npm run build`.
- Le backend tourne et est joignable (`http://<IP>:8000`) ?
- Ouvrez la console du navigateur (F12) pour voir les erreurs WebSocket/REST.

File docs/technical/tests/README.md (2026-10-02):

# 5 — Catalogue des scripts de test

Tous les scripts `test_*.py` sont à la **racine** du projet. Ils ont servi à
valider chaque brique, dans l'ordre, et restent les meilleurs outils de
diagnostic. Ce chapitre explique **quoi lancer, quand, et dans quel ordre**.

> ⚠️ **Sécurité** : pour tout test qui commande les moteurs, **surélevez le
> robot** (roues dans le vide) la première fois, ou placez‑le dans une zone
> dégagée. Gardez le bouton ARU et l'alimentation à portée de main.

> 🔴 **PROCÉDURE OBLIGATOIRE AVANT CHAQUE TEST** : lancez d'abord
> **`test_encoders.py`** et **tournez chaque roue à la main** une par une pour
> vérifier que les tics des **4 encodeurs** augmentent. Les 4 encodeurs
> fonctionnent, mais la **carte de commande** a des problèmes intermittents :
> si une roue ne compte pas, **l'odométrie sera fausse** et tous les
> déplacements asservis seront erronés. Repositionnez / vérifiez la carte tant
> que les 4 roues ne comptent pas correctement.

> La plupart des scripts prennent le **port série** en argument
> (`/dev/serial0`, `/dev/serial/by-id/...` sur la Pi, `COMx` sous Windows) et
> ont des options (`--vx`, `--duration`, `--cycles`, …). Lancez‑les avec
> `--help` ou lisez leur docstring en tête de fichier.

## Parcours recommandé (du plus simple au plus complet)

```
0. test_encoders.py      → ⭐ AVANT CHAQUE TEST : vérifier que les 4 roues comptent
1. test_comm.py          → la liaison Pi↔STM32 marche, les moteurs bougent
2. test_encoders.py      → (re)vérifier les encodeurs après toute manip carte
3. test_motor_mapping.py → quelle roue correspond à quel moteur/encodeur
4. test_odom.py          → l'odométrie mesure correctement les vitesses
5. test_move_to.py       → l'asservissement de position converge
6. test_ax12.py          → le servo du prisme se déploie/replie
7. test_xbee.py          → la station Topcon répond via XBee
8. test_codeprincipale_ms → enchaînement déplacement + mesure station
```

## Détail des scripts

### `test_comm.py` — liaison et mouvements de base 🟢
Envoie une séquence de `CMD_SET_VELOCITY` : avant, arrière, (rotation),
chacun pendant `--duration` s, avec un STOP entre chaque. **Le premier test à
lancer** pour vérifier que la chaîne Pi → STM32 → Sabertooth fonctionne.
```bash
python test_comm.py COM6 --vx 0.08 --duration 2 --pause 1
```

### `test_encoders.py` — validation des encodeurs (étape 1) ⭐ À LANCER AVANT CHAQUE TEST
Ne commande **pas** les moteurs : on **pousse / tourne chaque roue à la main**
et on lit la pose et les compteurs. Permet de vérifier : que les **4 encodeurs
comptent** (essentiel — voir l'encadré en haut de page), le sens de chaque
encodeur, l'échelle (`TICKS_PER_METER`), le signe de θ.
**C'est le contrôle de routine indispensable** : la carte de commande étant
intermittente, une roue qui ne compte pas fausse toute l'odométrie.

### `test_motor_mapping.py` — diagnostic du mapping moteurs/encodeurs
Utilise des combinaisons vx/vy qui isolent des **paires de roues** grâce à la
cinématique mecanum (ex. vx=+v, vy=+v → seules FR et RL tournent). Sert à
établir quel Sabertooth pilote quelle roue et à vérifier les polarités. **C'est
ce script qui a fixé le mapping documenté dans `robot_config.h` (2026‑05‑22).**

### `test_odom.py` — validation odométrie en vitesse (étape 2)
Pour chaque direction et chaque vitesse, envoie une consigne, échantillonne
`GET_STATUS`, et calcule le ratio vitesse mesurée / vitesse commandée et la
distance parcourue. Permet de **calibrer `TICKS_PER_METER`**.

### `test_move_to.py` — asservissement de position (étape 3)
Envoie une coordonnée absolue (x, y) et suit la convergence du contrôleur en
pollant `GET_STATUS`. **Commencez par des cibles très petites (≤ 5 cm)** tant
que la calibration n'est pas sûre.

### `test_ax12.py` — servo du prisme 🟢
Déploie puis replie le prisme via `CMD_DEPLOY_PRISM` / `CMD_RETRACT_PRISM`,
avec option de boucle sur N cycles. Vérifie le bon fonctionnement mécanique du
bras.
```bash
python test_ax12.py COM6 --cycles 3 --pause 2.0
```

### `test_robotf.py`, `test_robotf2.py` — tests moteurs interactifs
Tests interactifs des paires de roues en diagonale (isolables via la
cinématique). `test_robotf2` est une évolution de `test_robotf`.

### `test_robotf3.py` — test moteurs automatique
Enchaîne automatiquement 10 mouvements (diagonales, translations, rotations)
sans interaction clavier. Pratique pour une démonstration / vérification rapide.

### `test_robotf4.py` — test automatique **silencieux** ⚠️
Variante de `test_robotf3` qui **n'envoie aucune trame pendant le mouvement**
(pas de polling). Écrit spécifiquement pour **contourner le bug d'overrun
UART** : tout `GET_STATUS` envoyé pendant que le robot bouge risquait de bloquer
la réception du STM32. À lire absolument — sa docstring explique le bug en
détail (voir aussi [passation](../08_Passation/README.md)).

### `test_robotf5.py` — diagnostic bas niveau (firmware patché requis)
Pilote **une seule roue à la fois** via des commandes bas niveau
(`CMD_TEST_WHEEL`, `CMD_RAW_VELOCITY`) qui court‑circuitent PID/cinématique/odom.
⚠️ **Nécessite une version patchée du firmware** ajoutant ces commandes et un
`HAL_UART_ErrorCallback`. Ces commandes ne sont **pas** dans le firmware actuel
(`protocol.h`) — à réintégrer si vous voulez utiliser ce script.

### `test_xbee.py` — diagnostic station Topcon via XBee 🟡
Vérifie la liaison XBee ↔ station : ouverture du port, ACK, trame CSV de mesure.
Calque le protocole de `ms1ax.py`. Voir [Station Topcon](../04_Raspberry_Pi/Station_Topcon.md).

### `test_codeprincipale_ms.py` — enchaînement complet (déplacement + mesure)
Script proche du déroulé d'une mission : pilote la station (`readport`,
commandes) en coordination avec les déplacements. Précurseur du WebSocket de
mission du backend.

### `test_x.py` — banc d'essai station
Petit script de test de communication avec la station (mêmes briques que
`test_codeprincipale_ms.py`). Utilitaire de mise au point.

## Tableau récapitulatif

| Script | Cible | Moteurs ? | Station ? | État |
|---|---|---|---|---|
| `test_comm.py` | liaison + déplacements | oui | non | 🟢 |
| `test_encoders.py` | encodeurs (à la main) | non | non | 🟢 |
| `test_motor_mapping.py` | mapping roues | oui | non | 🟢 |
| `test_odom.py` | odométrie vitesse | oui | non | 🟡 |
| `test_move_to.py` | asservissement position | oui | non | 🟡 |
| `test_ax12.py` | servo prisme | non* | non | 🟢 |
| `test_robotf.py` / `f2` | moteurs interactif | oui | non | 🟡 |
| `test_robotf3.py` | moteurs auto | oui | non | 🟡 |
| `test_robotf4.py` | moteurs auto silencieux | oui | non | 🟢 |
| `test_robotf5.py` | roue par roue | oui | non | 🔴 firmware patché requis |
| `test_xbee.py` | liaison station | non | oui | 🟡 |
| `test_codeprincipale_ms.py` | déplacement + mesure | oui | oui | 🟡 |
| `test_x.py` | station (banc d'essai) | non | oui | 🟡 |

\* `test_ax12.py` commande le servo, pas les roues.

> **Conseil de reprise** : si vous repartez de zéro, refaites le parcours 1→6
> dans l'ordre pour reprendre confiance dans chaque brique avant d'attaquer une
> mission complète.

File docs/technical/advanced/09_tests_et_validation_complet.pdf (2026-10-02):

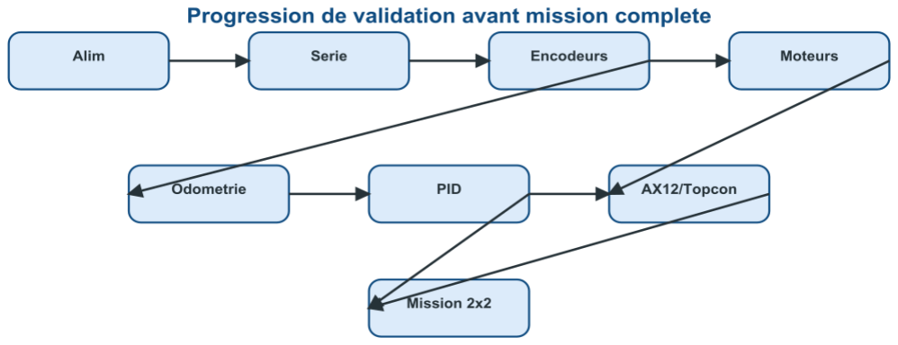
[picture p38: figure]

TopoBot - Documentation de passation - Juin 2026 | Page 1

# 09 - Tests et validation

### Documentation completee avec schemas, matrice de tests et journal de validation

Version | 1.1 - version completee avec schemas
Date | Juin 2026
Projet | TopoBot - ENSIM x ESGT
Usage | Passation technique pour la prochaine promotion

## Sommaire

1. Strategie de validation
2. Tests unitaires
3. Tests de deplacement
4. Tests AX12/Topcon
5. Mission reduite
6. Journal de validation

# 1. Strategie de validation

TopoBot combine plusieurs sous-systemes. Une mission complete ne doit etre lancee qu apres validation des briques simples. L ordre recommande limite les risques et facilite le diagnostic.

# 2. Tests materiels et communication

Test | Objectif | Resultat attendu
Alimentation | Verifier tensions, ARU, cartes | Aucune surchauffe, tensions coherentes
Port serie | Identifier STM32 et XBee | Chemins /dev/serial/by-id notes
GET_STATUS | Verifier protocole | STATUS recu sans CRC error
RESET_ODOM | Remise a zero | x=y=theta=0
STOP | Arret logiciel | Moteurs stoppes immediatement

# 3. Tests encodeurs et moteurs

Test | Procedure | Critere de validation
Encodeur roue par roue | Tourner chaque roue et lire E1..E4 | Chaque roue change un compteur unique

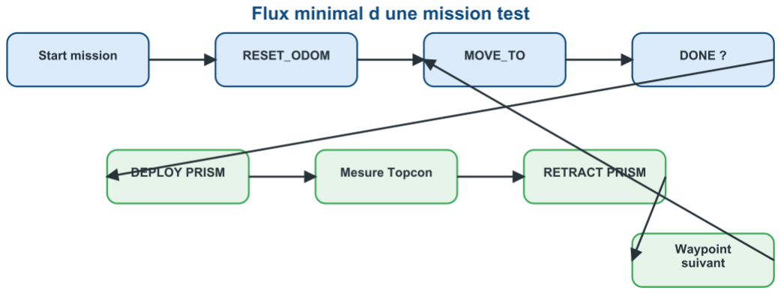
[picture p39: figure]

TopoBot - Documentation de passation - Juin 2026 | Page 2
Test | Procedure | Critere de validation
Signe encodeur | Tourner dans les deux sens | Signe coherent avec convention
Moteur unitaire | Commande faible par roue | Moteur correct, sens correct
Translation avant | MOVE_TO(0.2,0,0) | x augmente, y et theta restent faibles
Lateral | MOVE_TO(0,0.2,0) | y evolue, rotation limitee

# 4. Flux mission test

La mission reduite doit verifier l enchainement RESET_ODOM, MOVE_TO, attente DONE, eventuelle mesure, enregistrement SQLite et mise a jour WebSocket.

# 5. AX12 et Topcon

Sous-systeme | Test | Risque
AX12 | DEPLOY puis RETRACT a faible vitesse | Surcharge si mecanisme bloque
XBee | Commande simple a courte distance | Timeout ou mauvais port
Topcon | Mode standard puis tracking | Prisme non acquis
SQLite | Verifier export CSV | Donnees incomplètes ou format incorrect

# 6. Validation par zones croissantes

Niveau | Zone | Condition de passage
N0 | Robot immobile | GET_STATUS, STOP, RESET_ODOM OK
N1 | 0,2 m | Mouvements simples OK
N2 | 1 m | Odometrie coherente
N3 | 2 x 2 m | Mission reduite stable
N4 | 5 x 5 m | Dérive acceptable
N5 | 10 x 10 m puis plus | Fusion Topcon recommandee

# 7. Journal de test

Date | Test | Zone | Resultat | Probleme | Correction | Valide par

# 8. Verification de coherence

Les validations doivent etre formulees prudemment : un test reussi sur 2 x 2 m ne valide pas l objectif final 50 x 50 m. Les documents indiquent donc validation sur essais reduits lorsqu il n existe pas de preuve de grande zone.

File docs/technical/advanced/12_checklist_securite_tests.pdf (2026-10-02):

# Checklist securite et validation avant tests

Projet TopoBot - Documentation complementaire - Juin 2026

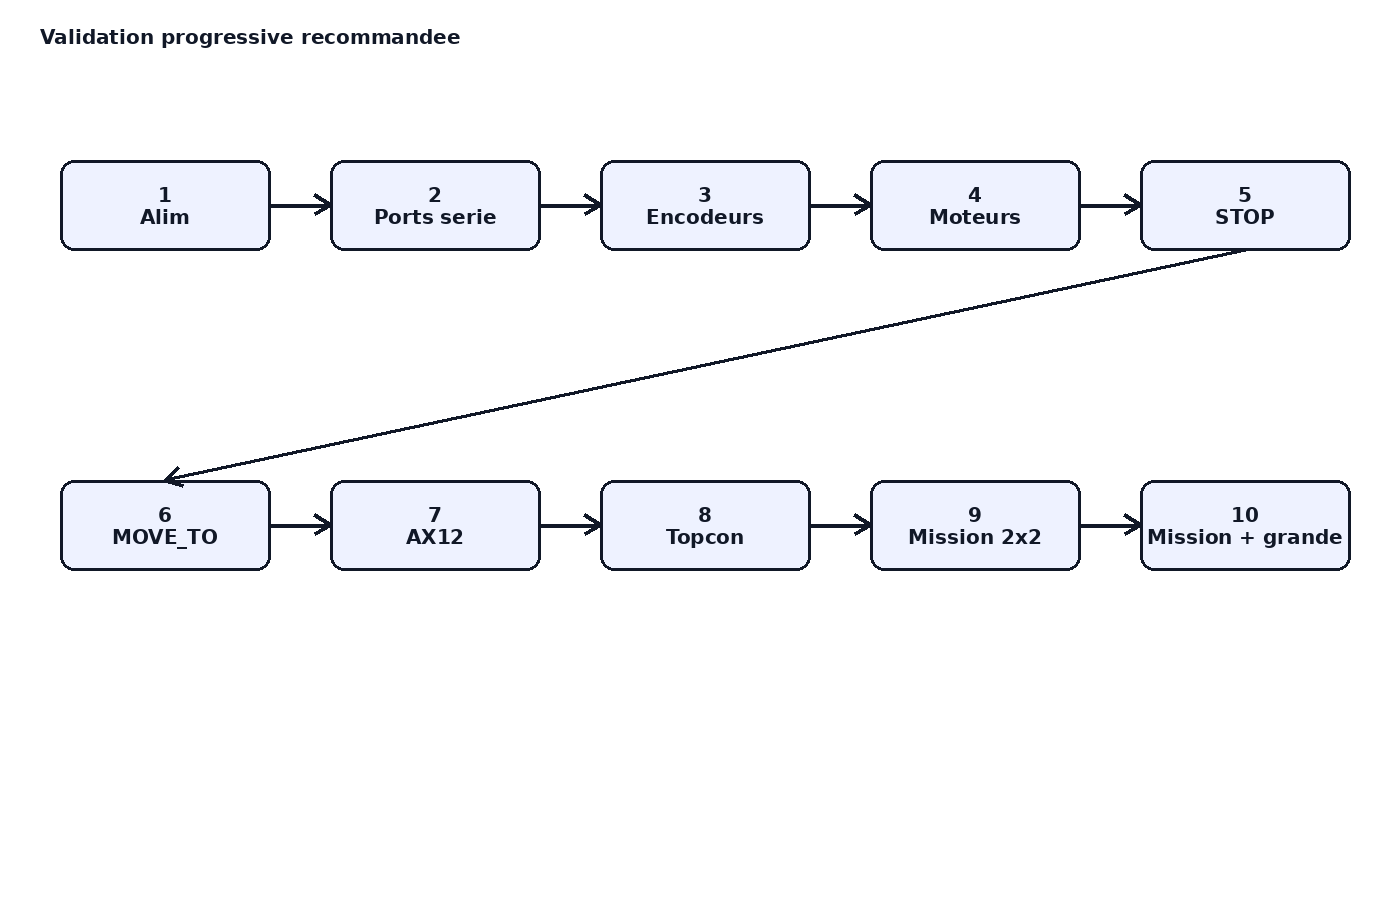
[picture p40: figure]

## Resume

Ce fichier complete les documents de passation deja produits pour faciliter la reprise du projet par la prochaine promotion. Les informations a confirmer sur le robot reel sont volontairement signalees.

## Objectif

Ce fichier est une liste de controle a imprimer ou a garder ouverte pendant les essais.

## Avant alimentation

Verifier les cables, les masses, les connecteurs, les roues, le prisme, la zone de test et la presence d un operateur pret a appuyer sur l ARU.

## Apres alimentation

Verifier Pi, STM32, Sabertooth, AX12, XBee, Topcon, tensions et absence de chauffe.

## Avant mouvement

Tester GET_STATUS, RESET_ODOM, STOP, puis tourner les roues a la main pour confirmer les encodeurs.

## Pendant mouvement

Commencer a basse vitesse, rester pres du robot, garder le bouton STOP accessible, ne pas tester pres d une marche.

## Apres test

Sauvegarder les logs, noter les symptomes, remplir le journal de test et ne modifier qu un parametre a la fois.

## Conclusion

Ce document doit rester vivant : chaque nouvelle validation, correction ou changement de cablage doit etre reporte dans la documentation pour eviter les pertes de temps lors de la reprise.

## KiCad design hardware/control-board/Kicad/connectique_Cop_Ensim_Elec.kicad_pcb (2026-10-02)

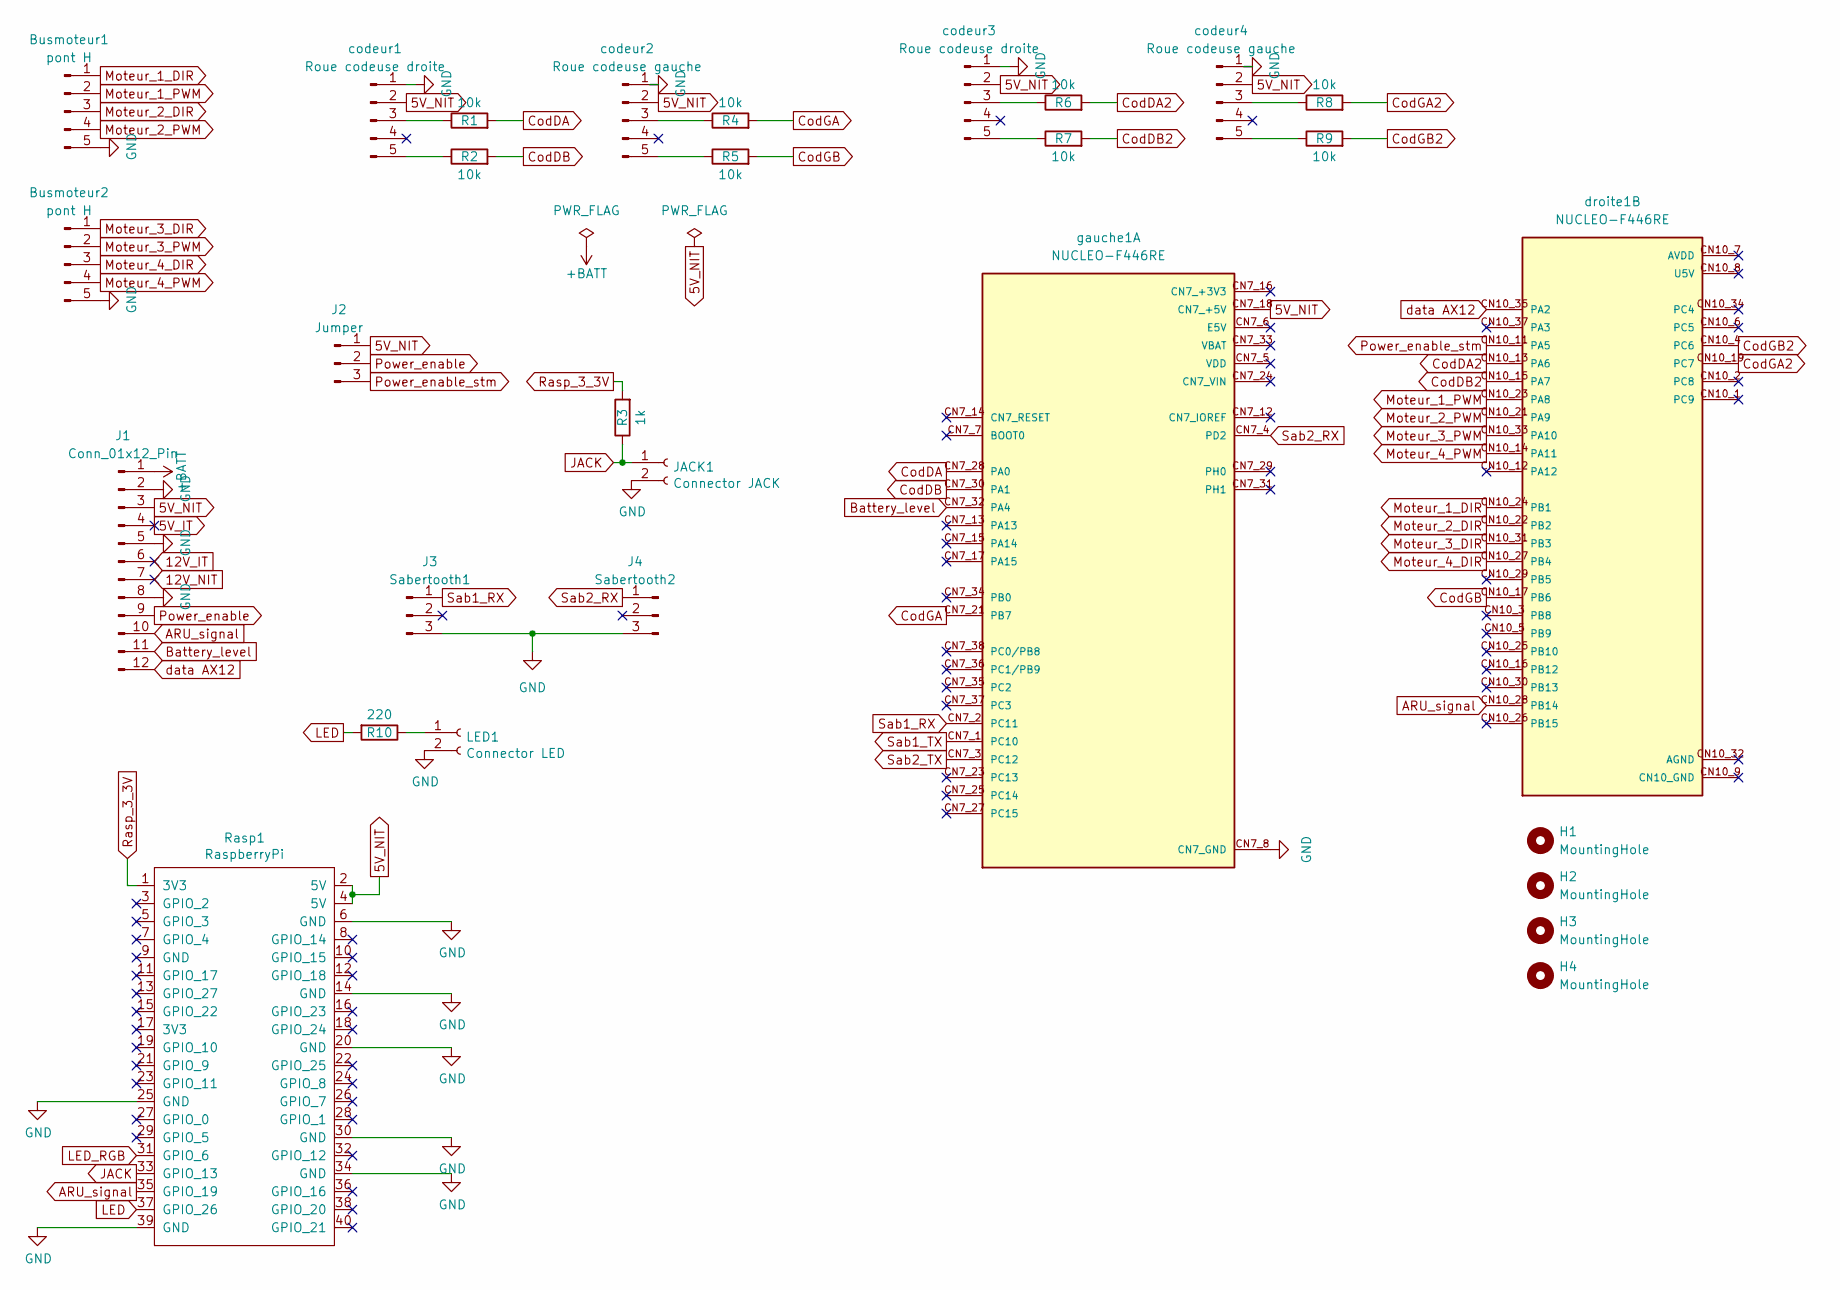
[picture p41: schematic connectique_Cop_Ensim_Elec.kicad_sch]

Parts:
Busmoteur1, Busmoteur2: pont H; JST_PH_B5B-PH-K_1x05_P2.00mm_Vertical
H1, H2, H3, H4: MountingHole; MountingHole_3.2mm_M3_DIN965_Pad
J1: Conn_01x12_Pin; PinHeader_1x12_P2.54mm_Vertical
J2: Jumper; PinHeader_1x03_P2.54mm_Vertical
J3: Sabertooth1; JST_PH_B3B-PH-K_1x03_P2.00mm_Vertical
J4: Sabertooth2; JST_PH_B3B-PH-K_1x03_P2.00mm_Vertical
JACK1: Connector JACK; JST_PH_B2B-PH-K_1x02_P2.00mm_Vertical
LED1: Connector LED; JST_PH_B2B-PH-K_1x02_P2.00mm_Vertical
R1, R2, R4, R5, R6, R7, R8, R9: 10k; R_Axial_DIN0207_L6.3mm_D2.5mm_P10.16mm_Horizontal
R3: 1k; R_Axial_DIN0207_L6.3mm_D2.5mm_P10.16mm_Horizontal
R10: 220; R_Axial_DIN0207_L6.3mm_D2.5mm_P10.16mm_Horizontal
Rasp1: RaspberryPi; MODULE_RASPBERRY_PI_4B_4GB
codeur1, codeur3: Roue codeuse droite; JST_PH_B5B-PH-K_1x05_P2.00mm_Vertical
codeur2, codeur4: Roue codeuse gauche; JST_PH_B5B-PH-K_1x05_P2.00mm_Vertical
droite1: NUCLEO-F446RE; MODULE_NUCLEO-F446RE droite; PARTREV 13; DigiKey_Part_Number 497-15882-ND
gauche1: NUCLEO-F446RE; MODULE_NUCLEO-F446RE gauche; PARTREV 13; DigiKey_Part_Number 497-15882-ND

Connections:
5V_IT: J1.4
5V_NIT: J1.3, J2.1, Rasp1.2 (5V), Rasp1.4 (5V), codeur1.2, codeur2.2, codeur3.2, codeur4.2, gauche1.CN7_18 (CN7_+5V)
12V_IT: J1.6
12V_NIT: J1.7
+BATT: J1.1
ARU_signal: J1.10, Rasp1.35 (GPIO_19), droite1.CN10_28 (PB14)
Battery_level: J1.11, gauche1.CN7_32 (PA4)
CodDA: R1.2, gauche1.CN7_28 (PA0)
CodDA2: R6.2, droite1.CN10_13 (PA6)
CodDB: R2.2, gauche1.CN7_30 (PA1)
CodDB2: R7.2, droite1.CN10_15 (PA7)
CodGA: R4.2, gauche1.CN7_21 (PB7)
CodGA2: R8.2, droite1.CN10_19 (PC7)
CodGB: R5.2, droite1.CN10_17 (PB6)
CodGB2: R9.2, droite1.CN10_4 (PC6)
GND: Busmoteur1.5, Busmoteur2.5, J1.2, J1.5, J1.8, J3.3, J4.3, JACK1.2, LED1.2, Rasp1.6 (GND), Rasp1.14 (GND), Rasp1.20 (GND), Rasp1.25 (GND), Rasp1.30 (GND), Rasp1.34 (GND), Rasp1.39 (GND), codeur1.1, codeur2.1, codeur3.1, codeur4.1, gauche1.CN7_8 (CN7_GND), gauche1.CN7_19 (CN7_GND), gauche1.CN7_20 (CN7_GND), gauche1.CN7_22 (CN7_GND)
JACK: JACK1.1, R3.1, Rasp1.33 (GPIO_13)
LED: R10.2, Rasp1.37 (GPIO_26)
LED_RGB: Rasp1.31 (GPIO_6)
Moteur_1_DIR: Busmoteur1.1, droite1.CN10_24 (PB1)
Moteur_1_PWM: Busmoteur1.2, droite1.CN10_23 (PA8)
Moteur_2_DIR: Busmoteur1.3, droite1.CN10_22 (PB2)
Moteur_2_PWM: Busmoteur1.4, droite1.CN10_21 (PA9)
Moteur_3_DIR: Busmoteur2.1, droite1.CN10_31 (PB3)
Moteur_3_PWM: Busmoteur2.2, droite1.CN10_33 (PA10)
Moteur_4_DIR: Busmoteur2.3, droite1.CN10_27 (PB4)
Moteur_4_PWM: Busmoteur2.4, droite1.CN10_14 (PA11)
unnamed: LED1.1, R10.1
unnamed: R1.1, codeur1.3
unnamed: R2.1, codeur1.5
unnamed: R4.1, codeur2.3
unnamed: R5.1, codeur2.5
unnamed: R6.1, codeur3.3
unnamed: R7.1, codeur3.5
unnamed: R8.1, codeur4.3
unnamed: R9.1, codeur4.5
Power_enable: J1.9, J2.2
Power_enable_stm: J2.3, droite1.CN10_11 (PA5)
Rasp_3_3V: R3.2, Rasp1.1 (3V3)
Sab1_RX: J3.1, gauche1.CN7_2 (PC11)
Sab1_TX: gauche1.CN7_1 (PC10)
Sab2_RX: J4.1, gauche1.CN7_4 (PD2)
Sab2_TX: gauche1.CN7_3 (PC12)
data AX12: J1.12, droite1.CN10_35 (PA2)

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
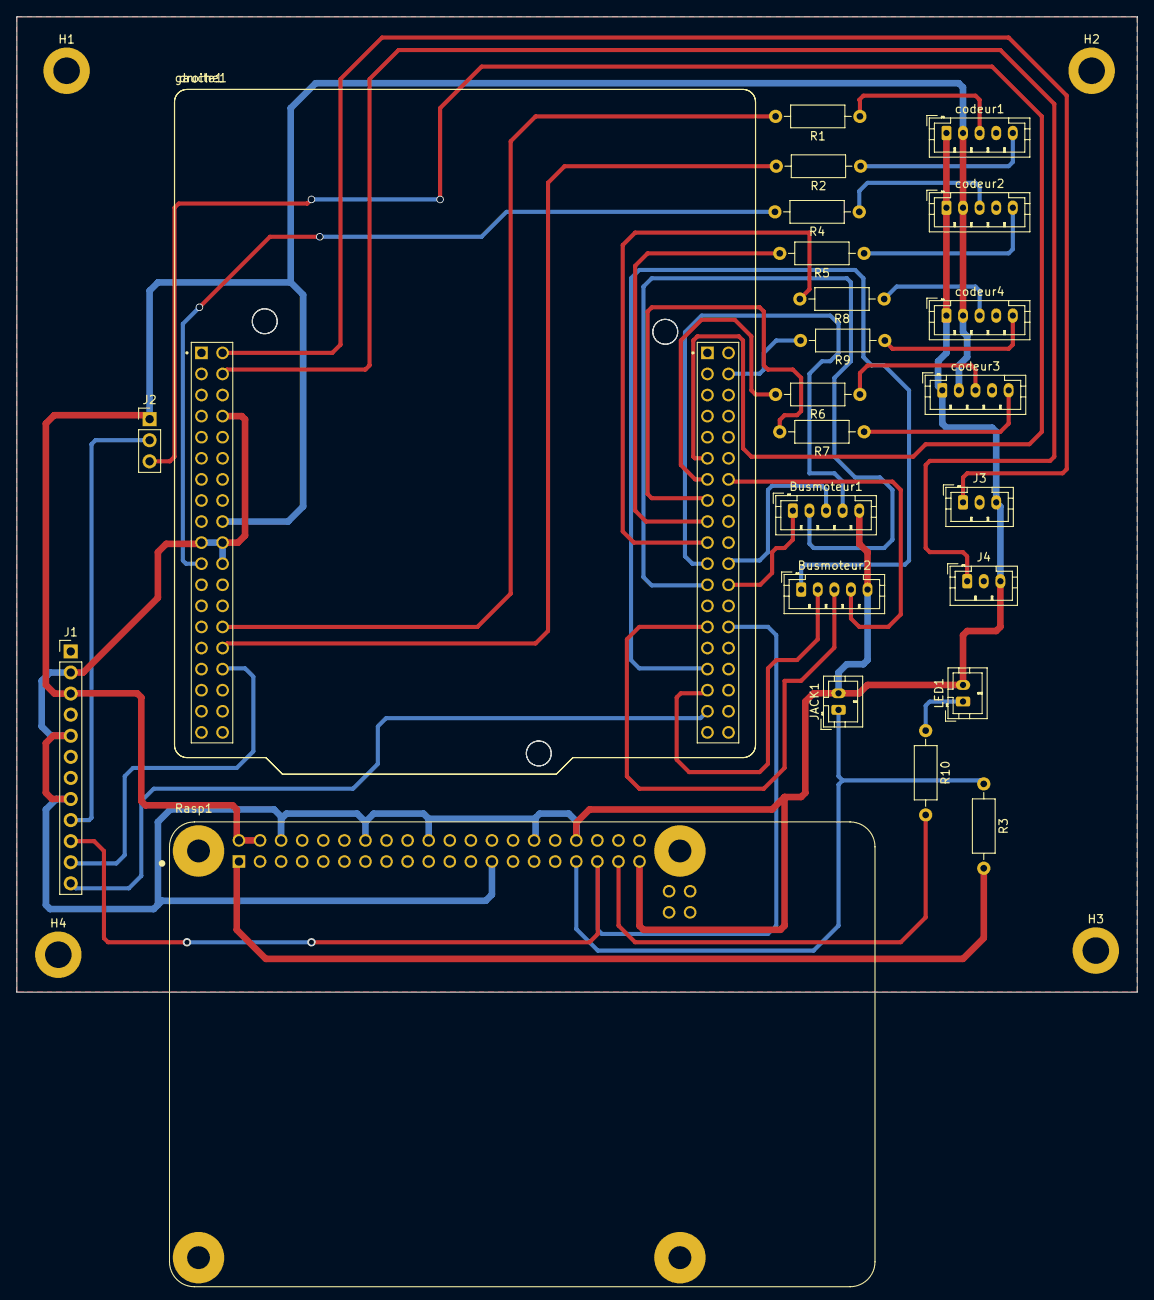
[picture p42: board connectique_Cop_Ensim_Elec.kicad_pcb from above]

Board: 2 copper layers, 135.0 x 117.5 mm, 29 parts (0 on the bottom side), 37 nets.

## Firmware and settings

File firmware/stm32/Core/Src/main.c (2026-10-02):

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
/* Includes ------------------------------------------------------------------*/
#include "main.h"

/* USER CODE BEGIN Includes */

#include "protocol.h"
#include "mecanum.h"
#include "odometry.h"
#include "robot_config.h"
#include "robot_control.h"
#include "ax12.h"
/* USER CODE END Includes */

ADC_HandleTypeDef hadc1;

TIM_HandleTypeDef htim1;
TIM_HandleTypeDef htim2;
TIM_HandleTypeDef htim3;
TIM_HandleTypeDef htim4;
TIM_HandleTypeDef htim8;

UART_HandleTypeDef huart4;
UART_HandleTypeDef huart5;
UART_HandleTypeDef huart2;

/* USER CODE BEGIN PV */

/* TIM6 : base timer 100 Hz — déclaré ici car non généré par CubeMX */
TIM_HandleTypeDef htim6;

/* ---- MODE TEST MINIMAL ----
 * Consigne de vitesse courante, ré-envoyée toutes les 50 ms par la main loop.
 * Pas de PID, pas d'odométrie, pas de grille, pas d'ARU.
 * Le Pi envoie CMD_SET_VELOCITY pour modifier ces valeurs, CMD_STOP pour les remettre à zéro.
 * NB : seules vx/vy sont utilisées (pas de rotation).
 */
volatile float    g_vx = 0.0f;
volatile float    g_vy = 0.0f;
volatile float    g_wz = 0.0f;   /* reçu du Pi pour compat protocole, ignoré */
volatile uint8_t  velocity_tick = 0;

/* USER CODE END PV */

void SystemClock_Config(void);
static void MX_GPIO_Init(void);
static void MX_ADC1_Init(void);
static void MX_TIM1_Init(void);
static void MX_TIM2_Init(void);
static void MX_TIM3_Init(void);
static void MX_TIM4_Init(void);
static void MX_TIM8_Init(void);
static void MX_UART4_Init(void);
static void MX_UART5_Init(void);
static void MX_USART2_UART_Init(void);
/* USER CODE BEGIN PFP */

static void MX_TIM6_Init(void);

/* USER CODE END PFP */

/* USER CODE BEGIN 0 */

/**
  * @brief TIM6 Initialization — base timer 100 Hz pour la boucle de contrôle
  *
  * NB : TIM6 n'est pas configuré dans le .ioc, donc CubeMX ne génère pas
  * son MspInit. On active l'horloge et l'IRQ ici manuellement, sinon le
  * timer ne compte jamais et la boucle de contrôle 100 Hz ne tourne pas.
  */
static void MX_TIM6_Init(void)
{
  TIM_MasterConfigTypeDef sMasterConfig = {0};

  /* 1. Activer l'horloge du timer (sinon le compteur ne tourne pas) */
  __HAL_RCC_TIM6_CLK_ENABLE();

  htim6.Instance               = TIM6;
  htim6.Init.Prescaler         = 8399;  /* 84 MHz / 8400 = 10 kHz */
  htim6.Init.CounterMode       = TIM_COUNTERMODE_UP;
  htim6.Init.Period            = 99;    /* 10 kHz / 100 = 100 Hz  */
  htim6.Init.AutoReloadPreload = TIM_AUTORELOAD_PRELOAD_DISABLE;
  if (HAL_TIM_Base_Init(&htim6) != HAL_OK)
  {
    Error_Handler();
  }
  sMasterConfig.MasterOutputTrigger = TIM_TRGO_RESET;
  sMasterConfig.MasterSlaveMode     = TIM_MASTERSLAVEMODE_DISABLE;
  if (HAL_TIMEx_MasterConfigSynchronization(&htim6, &sMasterConfig) != HAL_OK)
  {
    Error_Handler();
  }

  /* 2. Activer l'interruption NVIC (priorité 1, plus haute que USART2=2) */
  HAL_NVIC_SetPriority(TIM6_DAC_IRQn, 1, 0);
  HAL_NVIC_EnableIRQ(TIM6_DAC_IRQn);
}

/* USER CODE END 0 */

/**
  * @brief  The application entry point.
  * @retval int
  */
int main(void)
{

  /* MCU Configuration--------------------------------------------------------*/

  /* Reset of all peripherals, Initializes the Flash interface and the Systick. */
  HAL_Init();

  /* Configure the system clock */
  SystemClock_Config();

  /* Initialize all configured peripherals */
  MX_GPIO_Init();
  MX_ADC1_Init();
  MX_TIM1_Init();
  MX_TIM2_Init();
  MX_TIM3_Init();
  MX_TIM4_Init();
  MX_TIM8_Init();
  MX_UART4_Init();
  MX_UART5_Init();
  MX_USART2_UART_Init();
  /* USER CODE BEGIN 2 */

  /* Init TIM6 (non géré par CubeMX) */
  MX_TIM6_Init();

  /* ---- ASSERVISSEMENT ACTIF : init complète ---- */
  RobotControl_Init();   /* initialise Odom (encodeurs) + Mecanum + PID, état IDLE */
  Protocol_Init();       /* lance la réception USART2 IT octet par octet */
  AX12_Init();           /* servo AX12 sur UART5 (PC12) */
  /* Activer l'alimentation puissance vers les Sabertooth (PA5) */
  HAL_GPIO_WritePin(Power_enable_stm_GPIO_Port, Power_enable_stm_Pin, GPIO_PIN_SET);

  /* TIM6 : tick périodique 100 Hz pour ré-émettre la consigne au Sabertooth */
  HAL_TIM_Base_Start_IT(&htim6);

  /* USER CODE END 2 */

  /* Infinite loop */
  /* USER CODE BEGIN WHILE */
  while (1)
  {
    /* Traitement des trames Pi (CMD_SET_VELOCITY / CMD_STOP / CMD_GET_STATUS) */
    Protocol_Process();

    /* Keepalive Sabertooth + odométrie : à chaque tick TIM6 (100 Hz, dt = CONTROL_DT).
     * Tourne en main loop (pas en IRQ) → USART2 RX peut préempter normalement. */
    if (velocity_tick) {
        velocity_tick = 0;
        RobotControl_Update();
    }

    /* USER CODE END WHILE */

    /* USER CODE BEGIN 3 */
  }
  /* USER CODE END 3 */
}

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
/* USER CODE BEGIN 4 */

/**
 * Callback TIM6 @ 100 Hz → simple flag pour la main loop.
 * AUCUN travail bloquant ici : l'envoi Sabertooth (17 ms à 9600 baud) se fait
 * en main loop, ce qui permet à l'IRQ USART2 RX de préempter normalement.
 */
void HAL_TIM_PeriodElapsedCallback(TIM_HandleTypeDef *htim)
{
    if (htim->Instance == TIM6) {
        velocity_tick = 1;
    }
}

/**
 * Callback réception UART (1 octet reçu depuis Raspberry Pi)
 */
void HAL_UART_RxCpltCallback(UART_HandleTypeDef *huart)
{
    if (huart->Instance == USART2) {
        Protocol_UART_RxCallback();
    }
}

/* USER CODE END 4 */
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


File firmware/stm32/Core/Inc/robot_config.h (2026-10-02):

/**
 * robot_config.h
 * Configuration matérielle du robot - STM32F446RETx
 * À adapter selon votre câblage exact.
 *
 * Encodeurs (vérifié par test_motor_mapping.py 2026-05-22) :
 *   ENC FR : TIM2  (PA0=CH1, PA1=CH2) -> CodDA/CodDB    — HORS SERVICE
 *   ENC RR : TIM3  (PA6=CH1, PA7=CH2) -> CodDA2/CodDB2  — fonctionne
 *   ENC FL : TIM4  (PB6=CH1, PB7=CH2) -> CodGB/CodGA    — HORS SERVICE
 *   ENC RL : TIM8  (PC6=CH1, PC7=CH2) -> CodG2B/CodGA2  — fonctionne
 *
 *   Sabertooth 1 (FL+RL) : UART4   PC10=TX (S1 commun aux 2 Sabertooth)
 *   Sabertooth 2 (FR+RR) : UART4   PC10=TX (même fil, distingué par adresse 129)
 *   AX12 Dynamixel       : UART5   PC12=TX, PD2=RX
 *
 *   Raspberry Pi UART   : USART2  (PA2, full-duplex via ST-Link)
 *   AX12 Dynamixel      : UART5   (PC12=TX, PD2=RX)
 *
 *   ARU signal          : PB14
 */

#ifndef ROBOT_CONFIG_H
#define ROBOT_CONFIG_H

#include "main.h"

/* ===================== HANDLES TIMERS ENCODEURS ===================== */
/* Mapping vérifié par test_motor_mapping.py (2026-05-22) :
 *   Les encodeurs suffixés "2" (CodG2, CodD2) sont à l'ARRIÈRE.
 *   Les encodeurs sans suffixe (CodG, CodD) sont à l'AVANT.
 *
 *   TIM2  (PA0/PA1) = CodDA/CodDB   → FR (Front Right)  — HORS SERVICE
 *   TIM3  (PA6/PA7) = CodDA2/CodDB2 → RR (Rear Right)   — fonctionne
 *   TIM4  (PB6/PB7) = CodGB/CodGA   → FL (Front Left)   — HORS SERVICE
 *   TIM8  (PC6/PC7) = CodG2B/CodGA2 → RL (Rear Left)    — fonctionne
 *
 * NOTE : seuls TIM8 (RL) et TIM3 (RR) produisent des ticks.
 *        TIM4 (FL) et TIM2 (FR) sont en panne ou déconnectés.
 *        L'odométrie utilise uniquement les encodeurs arrière (ODOM_REAR_ONLY).
 */
#define ENC_FL_TIM      htim4   /* Front Left  = CodG  (Gauche)   — HORS SERVICE */
#define ENC_FR_TIM      htim2   /* Front Right = CodD  (Droite)   — HORS SERVICE */
#define ENC_RL_TIM      htim8   /* Rear Left   = CodG2 (Gauche 2) — fonctionne */
#define ENC_RR_TIM      htim3   /* Rear Right  = CodD2 (Droite 2) — fonctionne */

/* Polarité comptage encodeurs : +1 si ticks positifs = roue avance,
 * -1 si le compteur est inversé (signaux A/B permutés sur les canaux timer).
 * Droite (TIM2, TIM3) : CodDA sur CH1, CodDB sur CH2 → A/B normal  → +1
 * Gauche (TIM4, TIM8) : CodGB sur CH1, CodGA sur CH2 → A/B swappé  → -1
 * Vérifié par test_motor_mapping.py (Test C) : RL et RR cohérents en "avant". */
#define ENC_POL_FL      (-1)   /* TIM4 Gauche  : A/B swappé → inverser (HORS SERVICE) */
#define ENC_POL_FR      (-1)   /* TIM2 Droite  : compteur décroît en avant → inverser (HORS SERVICE) */
#define ENC_POL_RL      (-1)   /* TIM8 Gauche2 : A/B swappé → inverser */
#define ENC_POL_RR      (+1)   /* TIM3 Droite2 : A/B normal */

/* Période ARR des timers encodeurs (CubeMX → TIMx→Counter Period) */
#define ENC_TIMER_ARR   65535

/* ===================== HANDLES UART ===================== */
/* Bus Sabertooth Packetized Serial : S1 des deux Sabertooth en commun
 * sur PC10 (UART4_TX). Les deux contrôleurs sont distingués par leur
 * adresse (128 / 129) sur le même fil. */
#define SABRE1_UART         huart4   /* Sabertooth 1 (addr 128) : FL + RL */
#define SABRE2_UART         huart4   /* Sabertooth 2 (addr 129) : FR + RR — MÊME bus */
#define RASP_UART           huart2   /* Liaison série Raspberry Pi */
#define RASP_UART_BAUDRATE  115200U  /* Baud rate Raspberry Pi */
#define AX12_UART           huart5   /* UART dédiée AX12 Dynamixel (PC12=TX, PD2=RX) */

/* Adresses Sabertooth (mode Packetized Serial, configurées sur les DIP) */
#define SABRE1_ADDR     128
#define SABRE2_ADDR     129

/* ===================== AX12 DYNAMIXEL - UART5 DÉDIÉ =====================
 * L'AX12 utilise UART5 (PC12=TX, PD2=RX) — UART dédiée, pas de conflit
 * avec la Raspberry Pi (USART2).
 * ============================================================================= */
#define AX12_BAUDRATE       1000000U /* Baud rate AX12 (defaut usine = 1 Mbps) */
#define AX12_ID_PRISM       2        /* ID Dynamixel du servo porte-prisme */
#define AX12_POS_DEPLOY     700U     /* Position déployée  (0=0°, 1023=300°) */
#define AX12_POS_RETRACT    200U     /* Position rentrée */
#define AX12_TIMEOUT_MS     100U     /* Timeout réponse servo (ms) */

/* ===================== GPIO ARU ===================== */
#define ARU_GPIO_Port   GPIOB
#define ARU_GPIO_Pin    GPIO_PIN_14

/* ===================== ODOMÉTRIE : MODE ENCODEURS ===================== */
/* Seuls les encodeurs arrière (RL=TIM8, RR=TIM3) fonctionnent.
 * Mettre à 0 quand les encodeurs avant (FL=TIM4, FR=TIM2) seront réparés. */
#define ODOM_REAR_ONLY      1

/* ===================== DIMENSIONS ROBOT ===================== */
/* Rayon de roue (m) — À MESURER PRÉCISÉMENT : diamètre d'une roue / 2 */
#define WHEEL_RADIUS_M      0.076f    /* 76 mm (3 pouces) — vérifier ! */

/* Demi-empattement X (avant-arrière depuis centre, m) */
#define WHEEL_BASE_LX       0.110f

/* Demi-empattement Y (gauche-droite depuis centre, m) */
#define WHEEL_BASE_LY       0.18725f
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

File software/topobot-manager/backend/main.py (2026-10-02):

"""
=============================================================================
  TopoBot Manager — Backend FastAPI (avec station topographique Topcon)
=============================================================================

  Le robot se deplace en boustrophedon sur une grille X * Y.
  A chaque point il abaisse le prisme AX12, lance une mesure
  sur la station Topcon MS1AX (via XBee), sauvegarde les donnees
  brutes (Hz, V, distance) en base SQLite, puis remonte le prisme
  avant de passer au suivant. Le Z est calcule plus tard (trigo).

  Architecture :
    Tablette <──WebSocket/REST──> Raspberry Pi (ce serveur)
                                       │
                                  USART2 (115200)
                                  STM32 F446RE
                                  (protocole binaire)

  Parcours boustrophedon :
    Rangee 0 (y=0)    : x = 0 → x_max      (gauche a droite)
    Rangee 1 (y=step) : x = x_max → 0       (droite a gauche)
    Rangee 2 (y=2*step): x = 0 → x_max      (gauche a droite)
    ...

  Arret d'urgence :
    - Bouton physique PB14 sur STM32 → ROBOT_ESTOP + ERR_ARU
    - Bouton frontend → POST /stop → CMD_STOP + abort mission
=============================================================================
"""

import asyncio
import os
import sqlite3
import struct
import threading
import serial
import time
from datetime import datetime

from fastapi import FastAPI, WebSocket, WebSocketDisconnect
from fastapi.middleware.cors import CORSMiddleware
from fastapi.staticfiles import StaticFiles
from fastapi.responses import FileResponse
from pydantic import BaseModel

app = FastAPI(title="TopoBot Manager API")

app.add_middleware(
    CORSMiddleware,
    allow_origins=["*"],
    allow_credentials=True,
    allow_methods=["*"],
    allow_headers=["*"],
)


# =============================================================================
#  CONFIGURATION
# =============================================================================

STM32_PORT = "/dev/serial/by-id/usb-STMicroelectronics_STM32_STLink_0671FF554975495067025353-if02"
STM32_BAUD = 115200
# XBee relie en USB (adaptateur FTDI), plus sur les broches TX/RX (UART GPIO).
# /dev/ttyUSB0 = premier adaptateur USB-serie. Verifier le nom exact avec :
#   ls /dev/serial/by-id/      (chemin stable, recommande si plusieurs USB)
#   ou : dmesg | grep ttyUSB
TOPCON_PORT = "/dev/ttyUSB0"
TOPCON_BAUD = 9600

# =============================================================================
#  PROTOCOLE STM32 — identique a protocol.h
# =============================================================================

PROTO_START = 0xAA

CMD_MOVE_TO       = 0x01
CMD_STOP          = 0x02
CMD_RESET_ODOM    = 0x03
CMD_GET_STATUS    = 0x04
CMD_SET_GRID      = 0x05
CMD_DEPLOY_PRISM  = 0x10
CMD_RETRACT_PRISM = 0x11

RESP_ACK    = 0xA1
RESP_DONE   = 0xA2
RESP_STATUS = 0xA3
RESP_ERROR  = 0xA4

STATUS_FMT  = "<fffiiiiffffffB"
STATUS_SIZE = struct.calcsize(STATUS_FMT)

STATE_NAMES = {0: "IDLE", 1: "MOVING", 2: "SETTLING", 3: "DONE", 4: "ESTOP", 5: "ERROR"}
ERR_NAMES = {
    0x01: "ERR_CRC", 0x02: "ERR_UNKNOWN_CMD", 0x03: "ERR_BUSY",
    0x04: "ERR_OUT_BOUNDS", 0x05: "ERR_ARU", 0x06: "ERR_AX12",
}


# =============================================================================
#  ETAT GLOBAL
# =============================================================================

class MissionConfig(BaseModel):
    largeur_x: float
    longueur_y: float
    pas_mesure: float

current_mission = {"x": 10.0, "y": 10.0, "step": 1.0}

abort_flag = threading.Event()
stm32_lock = threading.Lock()


# =============================================================================
#  BASE DE DONNEES SQLITE
# =============================================================================

DB_PATH = os.path.join(os.path.dirname(__file__), "topobot.db")


def init_db():
    conn = sqlite3.connect(DB_PATH)
    c = conn.cursor()
    # Pas de Z : la station ne fournit que Hz, V et la distance.
    # Le Z (altitude) est calcule plus tard par formules trigonometriques.
    c.execute("""CREATE TABLE IF NOT EXISTS points
                 (id INTEGER PRIMARY KEY AUTOINCREMENT,
                  time TEXT, x REAL, y REAL,
                  hz REAL, v REAL, dist REAL)""")
    for col in ["hz REAL", "v REAL", "dist REAL"]:
        try:
            c.execute(f"ALTER TABLE points ADD COLUMN {col}")
        except sqlite3.OperationalError:
            pass
    conn.commit()
    conn.close()


init_db()


# =============================================================================
#  STATION TOPCON MS1AX — communication serie via XBee
# =============================================================================

def _read_topcon_line(ser: serial.Serial, timeout: float = 20.0) -> str:
    t_start = time.time()
    t_end = t_start + timeout
    bytes_total = 0
    print(f"[Topcon] Attente reponse (timeout={timeout}s, in_waiting={ser.in_waiting})...")

    while time.time() < t_end:
        if ser.in_waiting > 0:
            raw = ser.readline()
            bytes_total += len(raw)
            elapsed = time.time() - t_start
            hex_dump = " ".join(f"{b:02X}" for b in raw[:50])
            line = raw.decode("utf-8", errors="ignore").strip()

            print(f"[Topcon] [{elapsed:.1f}s] Recu {len(raw)} octets : {repr(line)}")
            print(f"[Topcon]   HEX: {hex_dump}")

            if not line:
                continue

            if "E" in line and len(line) < 5:
                print(f"[Topcon]   -> Erreur moteur/recherche, on ignore")
                time.sleep(0.5)
                continue

            if "," in line:
                print(f"[Topcon]   -> Trame CSV valide detectee apres {elapsed:.1f}s")
                return line

            print(f"[Topcon]   -> Pas de virgule, on continue d'ecouter...")
        else:
            time.sleep(0.1)

    elapsed = time.time() - t_start
    if bytes_total == 0:
        print(f"[Topcon] TIMEOUT ({elapsed:.1f}s) — Aucun octet recu. La station ne repond pas.")
    else:
        print(f"[Topcon] TIMEOUT ({elapsed:.1f}s) — {bytes_total} octets recus mais pas de trame CSV")
    return ""


def _topcon_init_tracking():
    """Reveil de la station + activation du mode tracking (poursuite).
    La station suit le prisme en continu pendant les deplacements du robot.
    """
    ser = get_topcon()
    with topcon_lock:
        print("[Topcon] === INIT TRACKING ===")
        ser.write(b"\r")
        time.sleep(0.2)
        ser.write(b"*PON\r\n")
        time.sleep(2)

        ser.write(b"*RM1\r\n")
        time.sleep(0.5)

        ser.write(b"*/PA 1,1,,\r\n")
        time.sleep(0.5)
        ser.write(b"*/PH 1\r\n")
        time.sleep(0.5)
        ser.write(b"Xe\r\n")
        time.sleep(0.5)

        ser.reset_input_buffer()
        ser.write(b"*ST2\r\n")
        ser.flush()
        time.sleep(0.5)
        ser.reset_input_buffer()
        print("[Topcon] === TRACKING ACTIF ===")
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

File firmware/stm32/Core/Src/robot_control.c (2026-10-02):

/**
 * robot_control.c
 *
 * Machine d'états + asservissement position 2 axes (x, y).
 * PAS d'asservissement angulaire : le robot ne déplace que sur les 4
 * axes cardinaux (AVANT/ARRIERE/GAUCHE/DROITE) sans tourner.
 *
 * Contrôleur P + saturation + zone morte :
 *   ex_r = (target_x - x)  projeté en repère robot
 *   ey_r = (target_y - y)  projeté en repère robot
 *   vx   = sat(KP * ex_r, ±VELOCITY_CAP)        ; |vx| < DEADBAND -> 0
 *   vy   = sat(KP * ey_r, ±VELOCITY_CAP)        ; |vy| < DEADBAND -> 0
 *
 * Choix proportionnel pur (pas de I ni D) pour :
 *   1. Garantir que toutes les roues reçoivent la même magnitude de cmd
 *      (donc tournent à la même vitesse) à tout instant.
 *   2. Eviter le pic dérivé du démarrage qui faisait diverger la pose.
 *   3. Rester dans la plage [DEADBAND, VELOCITY_CAP] où le Sabertooth
 *      répond uniformément (régime validé empiriquement à v=0.10 m/s).
 *
 * Convergence : pose dans POS_TOLERANCE_M pendant SETTLE_CYCLES cycles
 *               consécutifs -> RESP_DONE puis IDLE.
 */

#include "robot_control.h"
#include "robot_config.h"
#include "pid.h"
#include "odometry.h"
#include "mecanum.h"
#include "protocol.h"
#include <math.h>
#include <string.h>
#include <stdio.h>
extern volatile float g_vx;
extern volatile float g_vy;
extern volatile float g_wz;   /* recu du Pi mais ignore (pas de rotation) */

/* ------------------------------------------------------------------ */
/*  State                                                               */
/* ------------------------------------------------------------------ */

static RobotState_t state = ROBOT_IDLE;

static float target_x     = 0.0f;
static float target_y     = 0.0f;

static float grid_max_x   = 10.0f;
static float grid_max_y   = 10.0f;

static uint32_t settle_cnt = 0;

/* État rampe accélération (slew rate limiter) */
static float prev_cmd_vx = 0.0f;
static float prev_cmd_vy = 0.0f;

volatile int32_t enc1 = 0;
volatile int32_t enc2 = 0;
volatile int32_t enc3 = 0;
volatile int32_t enc4 = 0;

/* PID translation X / Y (rotation supprimée) — utilisés uniquement pour
 * leurs gains KP, le contrôleur est en réalité un P pur saturé/seuillé. */
static PID_t pid_x;
static PID_t pid_y;

/* Saturation à [lo, hi] */
static inline float saturate(float x, float lo, float hi)
{
    if (x < lo) return lo;
    if (x > hi) return hi;
    return x;
}

/* ---- Debounce ARU ----
 * Filtre les glitches EMI moteur sur PB14. L'ARU n'est considéré
 * actif qu'après ARU_DEBOUNCE_CYCLES lectures LOW consécutives à 100 Hz.
 */
#define ARU_DEBOUNCE_CYCLES   5    /* 50 ms à 100 Hz */
static uint32_t aru_low_count = 0;

/* ---- Keepalive Sabertooth ----
 * En IDLE/ESTOP/ERROR, on ré-envoie un paquet "stop" tous les
 * KEEPALIVE_CYCLES cycles pour ne pas perdre la liaison série
 * (timeout Sabertooth ~1 s → LED rouge sinon).
 */
#define KEEPALIVE_CYCLES      50   /* 500 ms à 100 Hz */
static uint32_t keepalive_count = 0;

/* ------------------------------------------------------------------ */
/*  Utilitaires                                                         */
/* ------------------------------------------------------------------ */

/** Lecture brute du pin ARU (sans debounce). Réservée à l'init du filtre
 *  ou aux décisions non-temps-réel où on accepte le risque de glitch. */
static bool aru_pin_low(void)
{
    return (HAL_GPIO_ReadPin(ARU_GPIO_Port, ARU_GPIO_Pin) == GPIO_PIN_RESET);
}

/** État ARU DEBOUNCÉ. Mis à jour par aru_filter_step() à chaque cycle 100 Hz. */
static bool aru_triggered(void)
{
    return (aru_low_count >= ARU_DEBOUNCE_CYCLES);
}

/** Avance le filtre debounce d'un cycle. À appeler une fois par RobotControl_Update().
 *  Compte les lectures LOW consécutives ; tout HIGH remet le compteur à zéro. */
static void aru_filter_step(void)
{
    if (aru_pin_low()) {
        if (aru_low_count < ARU_DEBOUNCE_CYCLES) aru_low_count++;
    } else {
        aru_low_count = 0;
    }
}

/** Vérifie que la position est dans la grille + marge */
static bool in_grid(float x, float y)
{
    /*float m = GRID_MARGIN_M;
    return (x >= -m) && (x <= grid_max_x + m)
        && (y >= -m) && (y <= grid_max_y + m);*/
	return true;
}

/* ------------------------------------------------------------------ */
/*  Init                                                                */
/* ------------------------------------------------------------------ */

void RobotControl_Init(void)
{
    /* On reutilise le contexte PID juste pour stocker les gains KP_x/KP_y
     * configurables a chaud via RobotControl_SetGains. Les termes I et D
     * sont neutralises (saturation -> P pur saturé applique en MOVING). */
    PID_Init(&pid_x, PID_X_KP, 0.0f, 0.0f, -VELOCITY_CAP, VELOCITY_CAP);
    PID_Init(&pid_y, PID_Y_KP, 0.0f, 0.0f, -VELOCITY_CAP, VELOCITY_CAP);

    Odom_Init();
    Mecanum_Init();

    state      = ROBOT_IDLE;
    settle_cnt = 0;
}

/* ------------------------------------------------------------------ */
/*  Boucle de contrôle (100 Hz)                                        */
/* ------------------------------------------------------------------ */
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

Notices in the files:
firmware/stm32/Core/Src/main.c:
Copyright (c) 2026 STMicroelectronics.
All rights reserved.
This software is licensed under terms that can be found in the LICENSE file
